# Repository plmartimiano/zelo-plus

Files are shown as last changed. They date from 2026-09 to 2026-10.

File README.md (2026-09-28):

# Zelo+ — Dispenser Inteligente de Medicamentos (firmware ESP32)

Protótipo de hardware/firmware do dispenser automático de medicamentos para idosos (pacientes)
do projeto acadêmico Zelo+. Projeto PlatformIO (framework Arduino, placa `esp32dev`).

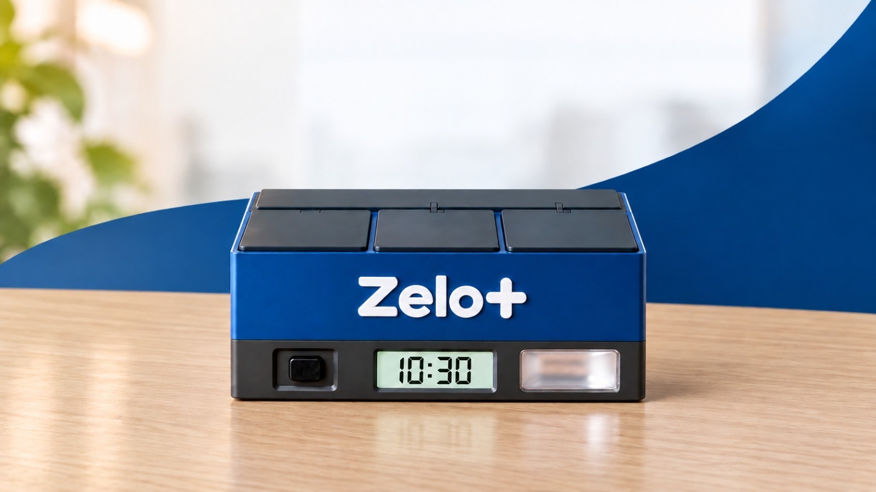
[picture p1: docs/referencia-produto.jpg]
Imagem de referência do produto Zelo+


*Imagem de referência — conceito visual do produto final (ilustrativo); não é o protótipo atual.*

Versão atual: **3 compartimentos** — até 3 medicamentos diferentes para o mesmo
paciente, cada um fixo no seu compartimento (detalhes em
[`docs/compartimentos.md`](docs/compartimentos.md)).

> 🛒 **Lista completa de componentes, com ilustrações e preços estimados:** Parte F do
> guia do produto.
> 📏 **Gabinete — 210 × 130 × 100 mm:** desenho técnico e imagens do produto na Parte B do
> guia do produto; vistas em escala em [`docs/gabinete.png`](docs/gabinete.png)
> ([SVG](docs/gabinete.svg)).
> 🏭 **Custo de produção em série (estimativa de viabilidade, set/2026):** Parte G do
> guia do produto — impressão 3D × plástico injetado, componentes no atacado e custo por
> unidade em 100, 1.000 e 10.000 unidades.
> 📘 **Guia do produto:** [`GUIA-DO-PRODUTO.md`](GUIA-DO-PRODUTO.md) explica o
> funcionamento passo a passo, com o trecho de código de cada etapa.
> Versão para impressão: [`docs/Zelo-Guia-do-Produto.pdf`](docs/Zelo-Guia-do-Produto.pdf).
> 🔌 **Ligações (bancada/testes):** [`docs/ligacoes.png`](docs/ligacoes.png) ([SVG](docs/ligacoes.svg)).
> 🔋 **Uso autônomo, após testes e atualização** — fonte 5 V/3 A + módulo **UPS LX-2BUPS** +
> baterias **18650** (lista de compras, montagem e teste) e relógio **DS3231**
> (opcional): Parte E do guia do produto e
> [`docs/ligacoes-autonomo.png`](docs/ligacoes-autonomo.png) ([SVG](docs/ligacoes-autonomo.svg)).

```
zelo-plus/
├── platformio.ini          # ambiente esp32dev + dependências
├── GUIA-DO-PRODUTO.md      # guia do produto
├── docs/compartimentos.md  # especificação aprovada dos 3 compartimentos
├── docs/ligacoes.png/.svg  # diagrama de todas as ligações (bancada)
├── docs/ligacoes-autonomo.*# montagem autônoma: fonte + módulo UPS + 18650 + DS3231
└── src/main.cpp            # firmware completo (máquina de estados + web + captive portal)
```

## Como compilar e gravar

1. Abra a pasta `zelo-plus/` no VSCode com a extensão PlatformIO.
2. Ajuste `upload_port` no `platformio.ini` (no Windows: Gerenciador de Dispositivos →
   "Silicon Labs CP210x USB to UART Bridge"), ou remova a linha para autodetecção.
3. `PlatformIO: Upload` e depois `PlatformIO: Monitor` (115200 baud).

## Fluxo de funcionamento

1. Cuidador acessa a página web servida pelo ESP32 e cadastra o paciente, até **3
   medicamentos** (um por compartimento, até 6 horários cada), cuidador, até 5
   familiares (opcionais) e o bot do Telegram.
2. A página indica onde colocar cada remédio ("Coloque LOSARTANA no compartimento 1").
   Cada compartimento que recebe um medicamento **novo** abre para abastecimento, **um
   de cada vez**; só mudar horários não abre nada.
3. O compartimento fecha pelo botão físico (trava de 7 s contra toque duplo) ou
   sozinho após 3 minutos.
4. No horário: buzzer + LED piscando e, no LCD, nome e compartimento do remédio
   (alternando se houver mais de um).
5. Paciente aperta o botão **uma vez** → alarme para e **todos os compartimentos daquela
   dose abrem**, um servo logo após o outro (nunca dois ao mesmo tempo).
   Se não aparecer, o alarme segue o ciclo de avisos (ver abaixo).
6. Paciente retira os remédios e fecha pelo botão (um toque fecha todos, após a trava
   de 7 s) ou timeout de 3 min.
7. Repete todo dia nos mesmos horários. Um horário que chega com algum compartimento
   aberto espera ele fechar e toca em seguida.
8. **Reposição:** a página pergunta qual medicamento será reposto, confirma e abre
   **só o compartimento dele**.
9. **Esvaziar compartimento:** apaga o cadastro daquele medicamento e, se o cuidador
   quiser, abre o compartimento para retirar as sobras.

## Hardware e pinagem

| Função | GPIO |
|---|---|
| Buzzer (ativo) | 15 |
| LED (+ resistor 220–330 Ω) | 4 |
| Botão (INPUT_PULLUP, outra perna no GND) | 5 |
| Servo compartimento 1 (sinal) | 13 |
| Servo compartimento 2 (sinal) | 14 |
| Servo compartimento 3 (sinal) | 27 |
| LCD I2C 16x2 (PCF8574, `0x27`) — SDA | 21 |
| LCD I2C — SCL | 22 |

- Servos: 0° = fechado, 90° = aberto (ajustáveis por compartimento em
  `ANGULO_FECHADO` / `ANGULO_ABERTO`). **Alimentação externa de 5 V (≥ 2 A)**, com GND
  compartilhado com o ESP32; o firmware nunca move dois servos ao mesmo tempo.
- O GPIO 12 foi evitado: ele interfere na inicialização do ESP32.
- Etiquetas **1, 2 e 3** na caixa, na mesma ordem da página.
- LCD: GND→GND, VCC→3V3, SDA→21, SCL→22.

## Relógio DS3231 (opcional)

Módulo RTC no mesmo I2C do LCD, em paralelo (`0x68`): VCC→3V3, GND→GND, SDA→21,
SCL→22, bateria **LIR2032**. Biblioteca `adafruit/RTClib`.

- **Sem o módulo:** `rtc.begin()` falha ao ligar e tudo segue pela hora da internet
  (NTP), como antes. O módulo pode ser instalado depois, sem regravar o firmware
  (com o dispenser desligado).
- **Ao ligar:** se o módulo tem hora válida (`!lostPower()` e data ≥ 2024), acerta o
  relógio do ESP32 com `settimeofday()` antes do Wi-Fi.
- **Com internet:** a cada sincronização do NTP (callback do SNTP) a hora é gravada no
  módulo pelo `loop()`, sem disputar o I2C com o LCD. O módulo guarda UTC.
- **Sem internet ao ligar:** com rede salva e hora do módulo, entra no modo normal
  (LCD `Sem internet` / `Hora do relogio`), os alarmes funcionam e o Wi-Fi é tentado a
  cada 30 s. Sem o módulo, o comportamento continua o de antes (portal de configuração).
- O rodapé da página mostra "Relógio DS3231: conectado" ou "não instalado".

## Wi-Fi (captive portal)

Não há credenciais fixas no código. Sem rede salva (ou se a conexão falhar), o ESP32
cria a rede aberta **ZeloPlus-Config**; ao conectar, o celular abre a página em
`192.168.4.1`, onde o cuidador escolhe a rede e digita a senha. A rede fica salva em
`Preferences` (namespace `wifi`). O link "Trocar rede Wi-Fi" apaga a rede e reinicia no
modo de configuração.

## Persistência do cadastro

Tudo fica em `Preferences` (namespace `cadastro`) e é recarregado no `setup()`:

- `nome` — paciente;
- `m0_*`, `m1_*`, `m2_*` — medicamento de cada compartimento (`_nome`, `_tot`,
  `_hr`, `_mn`), ou seja, a ligação medicamento ↔ compartimento;
- `cuid_*` / `fam0_*` … `fam4_*` — contatos; `tg_token` — bot do Telegram.

O cadastro da versão de um compartimento (`remedio`, `total`, `horas`, `minutos`)
migra sozinho para o compartimento 1 na primeira vez que esta versão liga.

## Ciclo do alarme e avisos pelo Telegram

| Tempo desde o horário | O que acontece |
|---|---|
| 0–1 min, 2–3, 4–5, 6–7, 8–9, 10–11 | Buzzer + LED tocando |
| 1–2 min, 3–4, 5–6, 7–8, 9–10, 11–12 | Silêncio (o botão continua funcionando) |
| 6 min sem acesso | Telegram para o **cuidador**: Zelo+: Paciente “Nome” não acessou o medicamento das “HH:MM” horas (Losartana). |
| 12 min sem acesso | Alarme para; Telegram para **cuidador e familiares**: Zelo+: Paciente “Nome” não foi até o dispenser no horário das “HH:MM” (Losartana e Metformina). |
| Depois dos 12 min | LCD mostra "Dose pendente!"; o botão ainda abre os compartimentos da dose |
| Paciente acessa após um aviso | Quem foi avisado recebe "paciente acessou o dispenser às HH:MM" |

### Por que Telegram

Comparação das opções para o ESP32 enviar avisos:

- **Bot do Telegram (escolhido)** — gratuito, API oficial, sem limite de vagas,
  uma requisição HTTPS direto do ESP32. Cada pessoa só precisa abrir o bot e tocar
  em "Iniciar".
- **CallMeBot (WhatsApp)** — foi a primeira escolha, mas o serviço ficou lotado
  (sem vagas para novos números) e o plano gratuito é só para uso pessoal.
- **Twilio WhatsApp** — oficial e confiável, mas pago, exige número aprovado e
  modelos de mensagem aprovados pela Meta.
- **WhatsApp Cloud API (Meta)** — oficial, exige conta Business verificada,
  modelos aprovados e token que expira; complexo para rodar só no ESP32.

Para um produto real com WhatsApp, o caminho recomendado é o ESP32 avisar um
backend, e o backend enviar pela API oficial (Twilio ou Meta).

### Como configurar

1. **Uma vez só (cuidador):** no Telegram, abrir o **@BotFather**, enviar `/newbot`,
   escolher um nome e um usuário terminado em `bot` (ex.: `zelo_maria_bot`).
   Copiar o **token** e colar no campo "Token do bot" da página de cadastro.
2. **Cada pessoa** (cuidador e familiares) procura o bot no Telegram e toca em
   **Iniciar**.
3. Na página, tocar em **Buscar IDs do Telegram**: aparecem o nome e o ID de quem
   iniciou o bot nas últimas 24 horas. Copiar cada ID para o campo da pessoa e salvar.
4. Usar **Enviar mensagem de teste no Telegram** para conferir.

O token fica salvo na placa (Preferences, chave `tg_token`) e não é mostrado de
volta na página; deixar o campo em branco ao salvar mantém o token atual. A conexão
HTTPS não valida o certificado (`setInsecure`), o que é aceitável no protótipo, mas
deve ser revisto num produto.

## Histórico de doses

Cada vez que um alarme dispara, o Zelo+ cria **um registro por medicamento** com data,
horário, medicamento, compartimento e situação, guardado na placa (`Preferences`,
namespace `historico`, últimas 60 doses):

| Situação | Quando |
|---|---|
| Tomada no horário | Paciente apertou o botão antes do primeiro aviso (6 min; 30 s no modo teste) |
| Tomada com atraso | Apertou depois do primeiro aviso, inclusive depois do alerta final (o tempo de atraso é registrado) |
| Sem acesso | Alerta final enviado e ninguém apertou o botão |
| Tocando agora | Alarme em andamento |

Na página aparecem o **resumo dos últimos 7 dias** (percentual de adesão geral e por
medicamento, e contagem por situação), as **20 doses mais recentes** e o link **Baixar histórico completo
(planilha CSV)**, que abre no Excel/Google Planilhas (separador `;`, colunas
data, horário, medicamento, compartimento, situação e atraso). O botão
"Apagar histórico" limpa todos os registros.

Adesão = (doses tomadas no horário + com atraso) ÷ doses concluídas no período.

## Máquina de estados (`loop()`)

Os horários são conferidos a cada segundo em qualquer estado; se o dispenser estiver
ocupado, ficam em espera (`mascaraEmEspera`) e tocam quando ele voltar a `AGUARDANDO`.

- `AGUARDANDO` — relógio no LCD; inicia alarmes em espera e, depois, o abastecimento
  de compartimentos novos (`filaAbastecimento`, um de cada vez).
- `TOCANDO` — ciclo 1 min tocando / 1 min silêncio por até 12 min, com avisos aos 6 e 12 min.
- `PORTA_ABERTA_ESTADO` — compartimentos da dose abertos; botão (após 7 s) ou timeout
  de 3 min fecha todos.
- `ABASTECENDO` — um compartimento aberto para o cuidador (abastecer, repor ou esvaziar).

`modoConfig` separa o modo de configuração de Wi-Fi do modo normal.

## Limitações conhecidas

1. Um paciente e até 3 medicamentos (`NUM_COMPARTIMENTOS`).
2. Máximo de 6 horários por medicamento (`MAX_HORARIOS`).
3. O captive portal pode não abrir sozinho em alguns celulares (abrir o navegador
   manualmente funciona).
4. Sem HTTPS/autenticação: qualquer pessoa na mesma rede pode alterar o cadastro.
5. Envio de mensagens trava o dispenser por alguns segundos (até ~10 s por
   contato se a internet estiver lenta).
6. Se a placa reiniciar dentro do minuto de um alarme que já tocou, ele pode tocar de
   novo (o controle "já disparado" fica só em RAM).

## Decisões de projeto

- Página web no próprio ESP32, para o cuidador não mexer no firmware.
- Trava de 7 s no botão contra fechamento acidental por toque duplo.
- Abertura automática só quando um compartimento recebe medicamento novo.
- Cada medicamento fica fixo no seu compartimento; reposição escolhe o medicamento
  e abre só o compartimento dele, com confirmação.
- Dose com mais de um remédio: um único toque abre todos, servos em sequência.
- Wi-Fi configurável por portal, para replicar o dispositivo em outros locais.

## Próximos passos sugeridos

- Autenticação simples na página web.
- Integração com backend/app do cuidador para monitoramento remoto.
- Testar o captive portal em mais modelos de celular.
- Validar fiação/protoboard para uso contínuo (certificação, testes com ILPIs).

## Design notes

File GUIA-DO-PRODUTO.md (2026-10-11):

# Zelo+ — Guia do produto

> Este guia apresenta o dispenser inteligente de medicamentos Zelo+: a concepção do
> produto, o desenho técnico do gabinete, o funcionamento do programa (com o **trecho de
> código** de cada etapa; o arquivo completo está em [`src/main.cpp`](src/main.cpp)), a
> montagem para uso autônomo, a lista de componentes, a estimativa de custo de produção
> e as propostas de evolução com inteligência artificial.

<!-- so-github -->
Imagem de referência do produto Zelo+

*Imagem de referência — conceito visual do produto final (ilustrativo).*
<!-- /so-github -->

---

## Sumário

- [Missão, visão e valores](#missão-visão-e-valores)
- [Sumário executivo](#sumário-executivo)
- [Parte A — Entendendo o projeto](#parte-a--entendendo-o-projeto)
  - [A1. O que é o Zelo+](#a1-o-que-é-o-zelo)
  - [A2. Materiais e ligações](#a2-materiais-e-ligações)
  - [A3. Ambiente de desenvolvimento](#a3-ambiente-de-desenvolvimento)
  - [A4. Cinco conceitos antes de começar](#a4-cinco-conceitos-antes-de-começar)
  - [A5. A página do Zelo+ (tela completa)](#a5-a-página-do-zelo-tela-completa)
- [Parte B — Desenho técnico do gabinete](#parte-b--desenho-técnico-do-gabinete)
  - [B1. Desenho técnico dimensional](#b1-desenho-técnico-dimensional)
  - [B2. Imagens do produto](#b2-imagens-do-produto)
  - [B3. Critérios de projeto](#b3-critérios-de-projeto)
  - [B4. Onde fica cada componente](#b4-onde-fica-cada-componente)
  - [B5. Abertura de emergência sem energia](#b5-abertura-de-emergência-sem-energia)
  - [B6. Modelo 3D do gabinete e impressão](#b6-modelo-3d-do-gabinete-e-impressão)
- [Parte C — O código, passo a passo](#parte-c--o-código-passo-a-passo)
  - [Passo 1 — Bibliotecas e pinos](#passo-1--bibliotecas-e-pinos)
  - [Passo 2 — Estruturas de dados](#passo-2--estruturas-de-dados)
  - [Passo 3 — `setup()`: ligando tudo](#passo-3--setup-ligando-tudo)
  - [Passo 4 — Wi-Fi sem senha no código (captive portal)](#passo-4--wi-fi-sem-senha-no-código-captive-portal)
  - [Passo 5 — Modo normal: relógio pela internet e rotas da página](#passo-5--modo-normal-relógio-pela-internet-e-rotas-da-página)
  - [Passo 6 — Memória permanente (Preferences)](#passo-6--memória-permanente-preferences)
  - [Passo 7 — A página de cadastro](#passo-7--a-página-de-cadastro)
  - [Passo 8 — Salvando o cadastro](#passo-8--salvando-o-cadastro)
  - [Passo 9 — Movendo as portas (servos)](#passo-9--movendo-as-portas-servos)
  - [Passo 10 — O coração: `loop()` e a máquina de estados](#passo-10--o-coração-loop-e-a-máquina-de-estados)
  - [Passo 11 — Conferindo os horários](#passo-11--conferindo-os-horários)
  - [Passo 12 — O alarme tocando](#passo-12--o-alarme-tocando)
  - [Passo 13 — O paciente aperta o botão](#passo-13--o-paciente-aperta-o-botão)
  - [Passo 14 — Abastecer, repor e esvaziar](#passo-14--abastecer-repor-e-esvaziar)
  - [Passo 15 — Avisos pelo Telegram](#passo-15--avisos-pelo-telegram)
  - [Passo 16 — Histórico de doses](#passo-16--histórico-de-doses)
  - [Passo 17 — Escrevendo no LCD](#passo-17--escrevendo-no-lcd)
  - [Passo 18 — Modo de teste](#passo-18--modo-de-teste)
  - [Passo 19 — Relógio DS3231 (próxima etapa)](#passo-19--relógio-ds3231-próxima-etapa)
  - [Passo 20 — Leitura da caixa do remédio por foto (IA)](#passo-20--leitura-da-caixa-do-remédio-por-foto-ia)
  - [Passo 21 — Modo do cuidador: abrir pelo botão, sem o celular](#passo-21--modo-do-cuidador-abrir-pelo-botão-sem-o-celular)
- [Parte D — Juntando tudo](#parte-d--juntando-tudo)
  - [D1. Linha do tempo de uma dose](#d1-linha-do-tempo-de-uma-dose)
  - [D2. Referência rápida](#d2-referência-rápida)
- [Parte E — Uso autônomo, sem o laptop](#parte-e--uso-autônomo-sem-o-laptop)
  - [E1. Pré-requisitos e validação](#e1-pré-requisitos-e-validação)
  - [E2. Por que o laptop não é necessário](#e2-por-que-o-laptop-não-é-necessário)
  - [E3. A solução: fonte 5 V/3 A + módulo UPS + bateria 18650](#e3-a-solução-fonte-5-v3-a--módulo-ups--bateria-18650)
  - [E4. Lista de compras](#e4-lista-de-compras)
  - [E5. Montagem passo a passo](#e5-montagem-passo-a-passo)
  - [E6. Teste de falta de energia](#e6-teste-de-falta-de-energia)
  - [E7. Autonomia da bateria](#e7-autonomia-da-bateria)
  - [E8. Falta de energia e de internet](#e8-falta-de-energia-e-de-internet)
  - [E9. Módulo de relógio DS3231](#e9-módulo-de-relógio-ds3231)
  - [E10. Atualizar o programa depois de montado](#e10-atualizar-o-programa-depois-de-montado)
  - [E11. Procedimento de emergência](#e11-procedimento-de-emergência)
- [Parte F — Lista completa de componentes, com preços](#parte-f--lista-completa-de-componentes-com-preços)
  - [F1. Eletrônica do dispenser](#f1-eletrônica-do-dispenser)
  - [F2. Energia autônoma](#f2-energia-autônoma)
  - [F3. Montagem e ligações](#f3-montagem-e-ligações)
  - [F4. Relógio sem internet (próxima etapa)](#f4-relógio-sem-internet-próxima-etapa)
  - [F5. Ferramentas necessárias (fora do custo)](#f5-ferramentas-necessárias-fora-do-custo)
  - [F6. Resumo do investimento](#f6-resumo-do-investimento)
- [Parte G — Custo de produção (estimativa para viabilidade)](#parte-g--custo-de-produção-estimativa-para-viabilidade)
  - [G1. Premissas e método](#g1-premissas-e-método)
  - [G2. Volume de plástico do gabinete](#g2-volume-de-plástico-do-gabinete)
  - [G3. Gabinete em impressão 3D](#g3-gabinete-em-impressão-3d)
  - [G4. Gabinete em plástico injetado](#g4-gabinete-em-plástico-injetado)
  - [G5. Componentes eletrônicos no atacado](#g5-componentes-eletrônicos-no-atacado)
  - [G6. Custo por unidade em três escalas](#g6-custo-por-unidade-em-três-escalas)
  - [G7. Investimentos iniciais (uma vez só)](#g7-investimentos-iniciais-uma-vez-só)
  - [G8. Preço de venda e viabilidade](#g8-preço-de-venda-e-viabilidade)
  - [G9. Limitações da estimativa](#g9-limitações-da-estimativa)
- [Parte H — Evolução do produto: funcionalidades com inteligência artificial](#parte-h--evolução-do-produto-funcionalidades-com-inteligência-artificial)
  - [H1. Princípios de projeto](#h1-princípios-de-projeto)
  - [H2. Arquitetura proposta](#h2-arquitetura-proposta)
  - [H3. Funcionalidades propostas](#h3-funcionalidades-propostas)
  - [H4. Quadro-resumo dos impactos](#h4-quadro-resumo-dos-impactos)
  - [H5. Impactos gerais da mudança](#h5-impactos-gerais-da-mudança)
  - [H6. Etapas de implantação](#h6-etapas-de-implantação)
  - [H7. Modelo próprio de IA (etapa futura)](#h7-modelo-próprio-de-ia-etapa-futura)
- [Referências](#referências)

---

# Missão, visão e valores

<figure markdown="1">
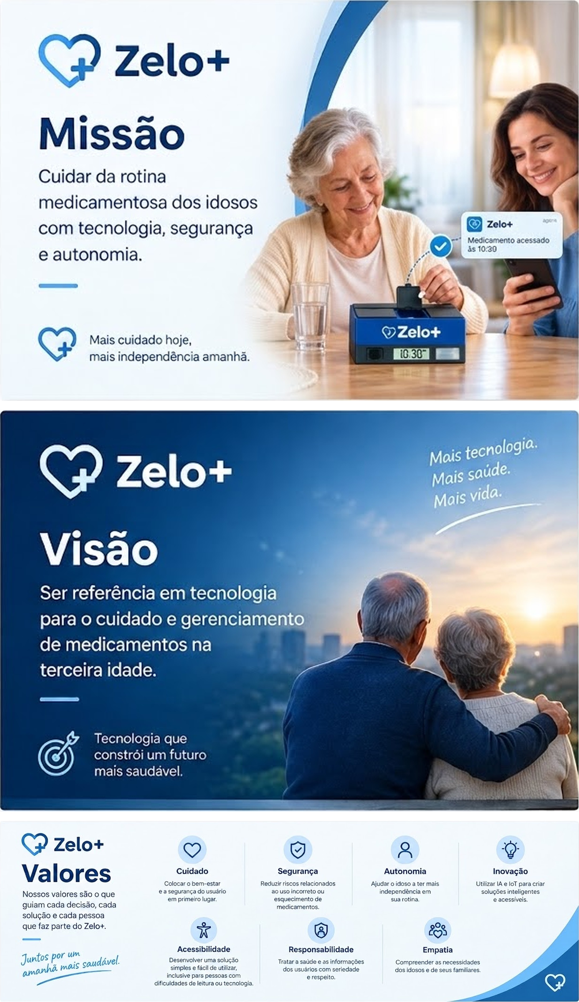
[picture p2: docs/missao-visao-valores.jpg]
Missão, visão e valores do Zelo+

<figcaption><b>Missão, visão e valores do Zelo+.</b></figcaption>
</figure>

---

# Sumário executivo

> O Zelo+ é um dispenser automático de medicamentos para idosos, com aviso ao cuidador
> pelo celular. Este sumário apresenta o problema tratado, o valor pretendido, a forma de
> entrega em ciclos curtos, os indicadores de sucesso, os riscos e os próximos marcos.
> O escopo detalhado é refinado a cada ciclo, com base no retorno de pacientes e
> cuidadores.

## Problema e necessidade

| Quem sofre | Dor |
|---|---|
| **Paciente idoso** | Uso de vários medicamentos em horários diferentes, com risco de esquecer doses, tomar em dobro ou confundir os remédios. |
| **Cuidador e família** | Falta de informação confiável sobre o que foi tomado e quando; o acompanhamento depende da memória do paciente ou de visitas. |
| **Profissional de saúde** | Ausência de dados objetivos de adesão ao tratamento na hora da consulta. |

**Oportunidade:** um dispositivo de mesa, simples para o paciente, que organiza as doses,
avisa no horário e mantém a família informada, a um custo compatível com o uso doméstico.

## Visão do produto e objetivos de valor

**Visão:** ser referência em tecnologia para o cuidado e o gerenciamento de medicamentos
na terceira idade.

| Objetivo de valor | Como o Zelo+ entrega hoje |
|---|---|
| **Dose certa, na hora certa** | Três compartimentos com porta motorizada; no horário, alarme sonoro, luz e mensagem colorida na tela; um botão abre somente o compartimento da dose. |
| **Família informada** | Aviso pelo Telegram quando a dose não é retirada (primeiro aviso aos 6 min e alerta final aos 12 min). |
| **Configuração sem técnico** | Página no celular para cadastrar remédios, horários e familiares, com abastecimento guiado e leitura da caixa do remédio por foto. |
| **Funciona mesmo sem internet** | Rede própria do dispenser quando o Wi-Fi da casa falha, novas tentativas automáticas e bateria para faltas de energia. |
| **Informação para a consulta** | Histórico de doses e taxa de adesão por medicamento, com exportação em planilha. |

## Abordagem e incrementos

A entrega é feita em **ciclos quinzenais**, cada um com um incremento utilizável e
validado em bancada ou com usuários, em vez de fases longas e sequenciais.

| Incremento | Valor entregue | Situação |
|---|---|---|
| **1. Núcleo do dispenser** | Alarmes, portas, botão, tela, página no celular, avisos pelo Telegram, histórico e adesão | Concluído (protótipo funcional) |
| **2. Robustez** | Montagem autônoma (fonte e bateria), relógio DS3231 para manter a hora sem internet, tempos definitivos de uso | Próximo ciclo |
| **3. IA — 1ª etapa** | Cadastro por foto ou código de barras, conferência na reposição e relatório de adesão (H3.1, H3.2, H3.6) | Leitura por foto já integrada; demais itens planejados |
| **4. IA — 2ª etapa** | Cadastro pela receita e assistente do cuidador no Telegram (H3.4, H3.7) | Planejado |
| **5. Acessibilidade** | Voz para o paciente (H3.11) | Planejado, depende de componente |
| **6. Modelo próprio de IA** | Leitura de embalagens sem serviço de terceiros (H7) | Horizonte de cerca de 12 meses |

## Indicadores de sucesso

| Indicador | Como medir | Meta proposta |
|---|---|---|
| **Adesão ao tratamento** | Doses tomadas ÷ doses previstas (histórico do próprio dispenser) | ≥ 90 % nos usuários do lote piloto |
| **Doses no horário** | Doses retiradas antes do primeiro aviso ÷ doses tomadas | Crescente a cada ciclo |
| **Tempo de reação da família** | Intervalo entre o alerta no Telegram e a retirada da dose | Redução a cada ciclo |
| **Facilidade de uso** | Tempo para cadastrar um remédio e taxa de tarefas concluídas sem ajuda | Cadastro em até 3 min |
| **Satisfação** | NPS de cuidadores e pacientes ao fim de cada ciclo de teste | NPS ≥ 50 |
| **Confiabilidade** | Falhas de porta, reinícios e horas sem hora certa por mês | Zero falha que impeça a dose |
| **Viabilidade** | Custo de fabricação por unidade (Parte G) | R$ 161–254 em série |

## Principais riscos e premissas

| Risco ou premissa | Estratégia de adaptação |
|---|---|
| **Enquadramento como dispositivo médico (Anvisa)** | Consulta regulatória antes da venda; funções de IA apenas informativas, sem bloquear ou alterar a prescrição. |
| **Proteção de dados de saúde (LGPD)** | Consentimento, envio mínimo de dados, chaves somente no serviço e opção de exclusão. |
| **Dependência de internet e de serviços de terceiros** | A rotina de doses funciona sem conexão; a IA é complementar e terá alternativa própria (H7). |
| **Falta de energia ou de hora certa** | Bateria com módulo UPS e relógio DS3231; aviso "Acerte a hora" e ajuste pelo celular; power bank na entrada USB-C e liberação manual das portas, sem energia (E11). |
| **Durabilidade mecânica** | Ensaios de ciclo de abertura; troca do SG90 pelo MG90S (engrenagem de metal) se necessário. |
| **Custo e câmbio** | Faixas de custo revisadas a cada ciclo; produção em lote piloto por impressão 3D antes de investir em moldes. |
| **Premissa de uso** | Paciente com autonomia para apertar um botão e cuidador com celular e Telegram; validada no lote piloto. |

## Próximos passos

| Marco | Entregas |
|---|---|
| **Próximo ciclo** | Montagem autônoma com fonte e bateria, relógio DS3231, tempos definitivos e ensaio completo da validação de pré-requisitos (E1). |
| **Release de validação** | Lote piloto de cerca de 100 unidades em impressão 3D, testes com famílias e coleta dos indicadores acima. |
| **Ciclos seguintes** | Etapas de IA conforme o retorno dos usuários, consulta regulatória e homologação na Anatel antes da comercialização. |

**Investimento de referência:** cerca de R$ 303–403 para montar um protótipo (Parte F);
custo de R$ 162–257 por unidade em série, com preço de venda estimado de R$ 400 a
R$ 1.030 (Parte G).

---

# Parte A — Entendendo o projeto

## A1. O que é o Zelo+

O Zelo+ é um **dispenser automático de medicamentos** para pacientes (em especial
idosos). Ele tem **3 compartimentos**, cada um com um remédio diferente e com uma
porta movida por um servo motor.

<figure markdown="1">
Imagem de referência do produto Zelo+
<figcaption><b>Imagem de referência</b> — conceito visual do produto final (ilustrativo), com o botão à esquerda, a tela no centro e a luz de alerta à direita.</figcaption>
</figure>

<figure markdown="1">
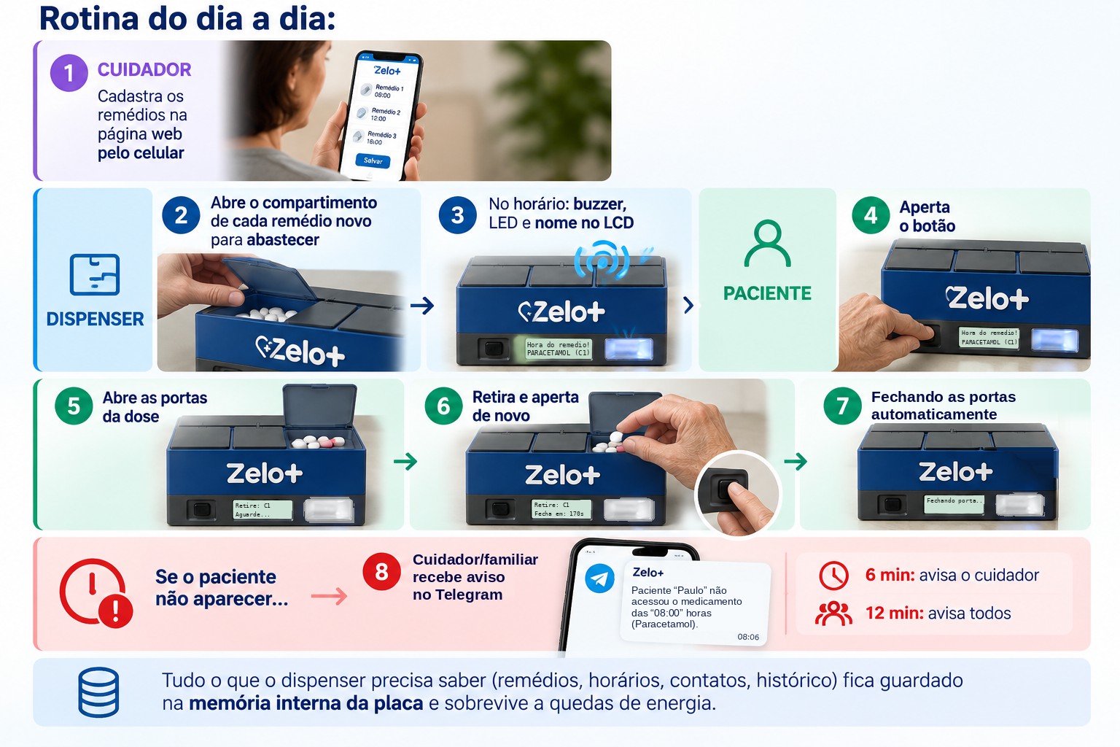
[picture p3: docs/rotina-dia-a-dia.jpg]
Rotina do dia a dia com o Zelo+

<figcaption><b>Rotina do dia a dia</b> — cuidador, dispenser e paciente, do cadastro dos remédios aos avisos pelo Telegram.</figcaption>
</figure>

## A2. Materiais e ligações

| Componente | Quantidade | Observação |
|---|---|---|
| ESP32 DevKit (30 pinos) | 1 | O "cérebro". Tem Wi-Fi embutido. |
| Servo motor SG90 | 3 | Um por compartimento (porta). |
| Tela TFT 2,25" colorida (ST7789P3, 76 × 284 pontos, ligação SPI) | 1 | Mostra relógio, nome do remédio e avisos, com cores por situação. |
| Buzzer **ativo** | 1 | Apita sozinho quando recebe energia. |
| LED + resistor 220–330 Ω | 1 | Pisca junto com o buzzer. |
| Botão (push-button) | 1 | O paciente aperta para abrir/fechar. |
| Fonte externa 5 V (≥ 2 A) | 1 | Alimenta os servos. |
| Relógio DS3231 + bateria LIR2032 *(próxima etapa)* | 1 | Guarda a hora sem internet ([Passo 19](#passo-19--relógio-ds3231-próxima-etapa)). |
| Protoboard e jumpers | — | Ligações. |

<figure markdown="1">
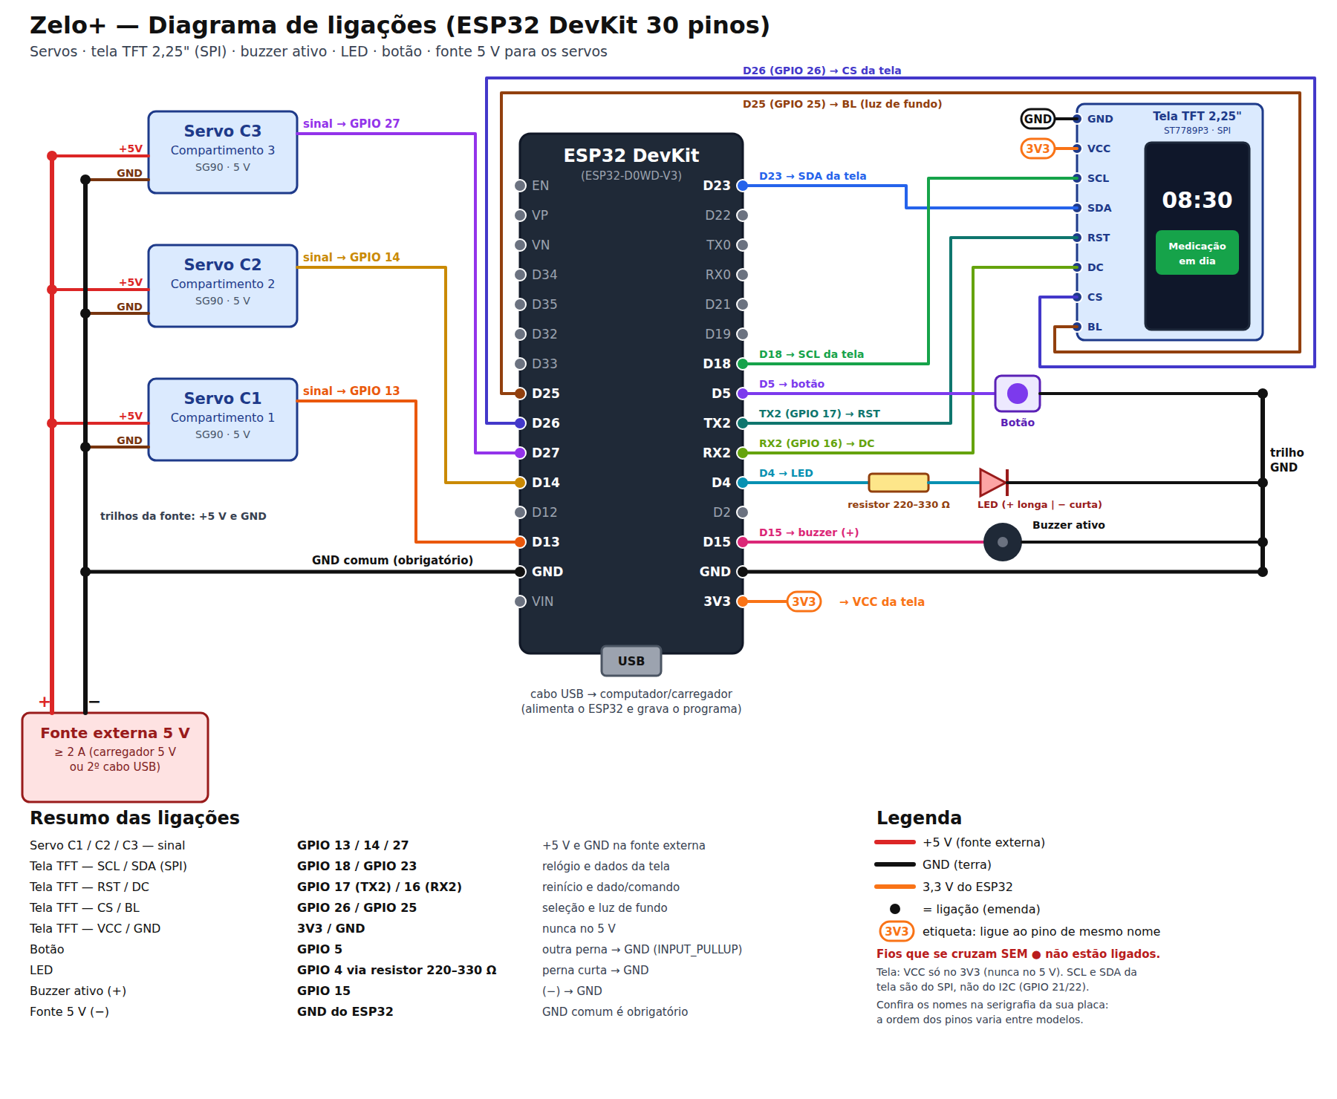
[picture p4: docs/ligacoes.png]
Diagrama de ligações do Zelo+

<figcaption><b>Diagrama de ligações da montagem de bancada.</b> Versão vetorial, que pode ser ampliada sem perda de qualidade: <code>docs/ligacoes.svg</code>.</figcaption>
</figure>

| Ligação | Pino do ESP32 | Detalhe |
|---|---|---|
| Servo compartimento 1 (sinal) | GPIO 13 | +5 V e GND na **fonte externa** |
| Servo compartimento 2 (sinal) | GPIO 14 | +5 V e GND na **fonte externa** |
| Servo compartimento 3 (sinal) | GPIO 27 | +5 V e GND na **fonte externa** |
| Tela TFT — SCL / SDA | GPIO 18 / GPIO 23 | relógio e dados do SPI |
| Tela TFT — RST / DC | GPIO 17 (TX2) / GPIO 16 (RX2) | reinício da tela / dado ou comando |
| Tela TFT — CS / BL | GPIO 26 / GPIO 25 | seleção da tela / luz de fundo |
| Tela TFT — VCC / GND | 3V3 / GND | **nunca no 5 V** |
| Relógio DS3231 — SDA / SCL *(próxima etapa)* | GPIO 21 / GPIO 22 | único no I2C; VCC → 3V3, GND → GND (desenho na [E3](#e3-a-solução-fonte-5-v3-a--módulo-ups--bateria-18650)) |
| Botão | GPIO 5 | outra perna → GND (sem resistor) |
| LED | GPIO 4 | via resistor; perna curta → GND |
| Buzzer (+) | GPIO 15 | (−) → GND |
| Fonte externa (−) | GND do ESP32 | **GND comum obrigatório** |

**Por que uma fonte separada para os servos?** Um servo puxa muita corrente no
momento em que começa a girar. Se ele for ligado no 3V3 do ESP32, a tensão cai e a
placa reinicia. Por isso os servos usam uma fonte de 5 V própria, e o **GND da fonte
é ligado ao GND do ESP32**: sem essa referência comum, o sinal do pino não é
entendido pelo servo.

**Ligação da tela TFT.** O módulo tem 8 pinos: GND, VCC, SCL, SDA, RST, DC, CS e BL.
Apesar dos nomes, **SCL e SDA da tela são do SPI** (relógio e dados), não do I2C: vão
nos GPIO 18 e 23, e não nos GPIO 21 e 22. Na placa, os GPIO 17 e 16 aparecem impressos
como **TX2** e **RX2**. O VCC vai no **3V3**: a tela trabalha com 3,3 V e pode ser
danificada no 5 V. O pino BL acende a luz de fundo; o ESP32 controla o brilho por ele.
O GPIO 19 fica reservado ao SPI, mesmo sem fio, e não deve ser usado para outra peça.

**Por que o GPIO 12 não foi usado?** Ele é um pino de "configuração de
inicialização" do ESP32; se estiver com algo ligado na hora de ligar a placa, ela
pode não iniciar.

## A3. Ambiente de desenvolvimento

- **VSCode** com a extensão **PlatformIO**.
- Placa `esp32dev`, framework **Arduino** (a mesma linguagem do Arduino, em C++).

O arquivo `platformio.ini` diz ao PlatformIO qual placa usar e quais bibliotecas
baixar:

```ini
[env:esp32dev]
platform = espressif32
board = esp32dev
framework = arduino
upload_port = COM3
monitor_speed = 115200
board_build.partitions = huge_app.csv
lib_deps = 
    marcoschwartz/LiquidCrystal_I2C^1.1.4
    madhephaestus/ESP32Servo^3.0.5
    bblanchon/ArduinoJson^7.0.4
    adafruit/RTClib^2.1.4
```

- `upload_port`: porta USB onde a placa aparece no Windows (varia de PC para PC).
- `monitor_speed`: velocidade do **Serial Monitor**, onde a placa escreve mensagens.
- `huge_app.csv`: reserva mais espaço para o programa (a parte de internet segura,
  HTTPS, deixa o firmware grande).
- `lib_deps`: bibliotecas do LCD, dos servos, de leitura de JSON (usada no Telegram)
  e do relógio DS3231 (`RTClib`).

**Para gravar:** ✓ (Build) → → (Upload) → 🔌 (Serial Monitor), na barra azul do
rodapé do VSCode.

## A4. Cinco conceitos antes de começar

1. **`setup()` e `loop()`** — todo programa Arduino tem essas duas funções. O
   `setup()` roda **uma vez** quando a placa liga; o `loop()` roda **para sempre**,
   milhares de vezes por segundo.

2. **`millis()` em vez de `delay()`** — `delay(1000)` congela a placa por 1 segundo
   (ela não lê o botão nem atende a página). Por isso o Zelo+ quase sempre usa
   `millis()`, que devolve "há quantos milissegundos a placa está ligada", e compara
   tempos:
   ```cpp
   if (millis() - ultimaAtualizacao < 1000) return;
   ```
   (se ainda não passou 1 segundo desde a última atualização, sai e tenta de novo
   na próxima volta do `loop()`, sem travar nada).

3. **Máquina de estados** — o dispenser está sempre em **um** estado (aguardando,
   tocando, porta aberta, abastecendo). Em cada estado ele faz coisas diferentes e,
   quando algo acontece, **muda de estado**. Isso deixa o comportamento previsível.

4. **Máscara de bits** — para dizer "compartimentos 1 e 3", o código usa um número
   em que cada **bit** representa um compartimento:
   ```text
   compartimento:   3 2 1
   bits:            1 0 1   = 5  →  compartimentos 1 e 3
   ```
   Assim uma única variável (`uint8_t`) guarda qualquer combinação de compartimentos.

5. **Memória permanente (Preferences/NVS)** — a variável comum some quando a energia
   cai. A biblioteca `Preferences` grava dados na **memória flash** da placa, que não
   se apaga ao desligar (como um pen drive).

## A5. A página do Zelo+ (tela completa)

É a página que o cuidador abre no celular, digitando o IP que aparece no LCD (ex.:
`192.168.15.152`). As imagens abaixo foram geradas **pelo próprio firmware** (a função
`handleRoot()` do Passo 7) com um cadastro de exemplo completo.

| ① Falta configurar o Telegram | ② Tudo configurado | ③ Blocos abertos |
|:---:|:---:|:---:|
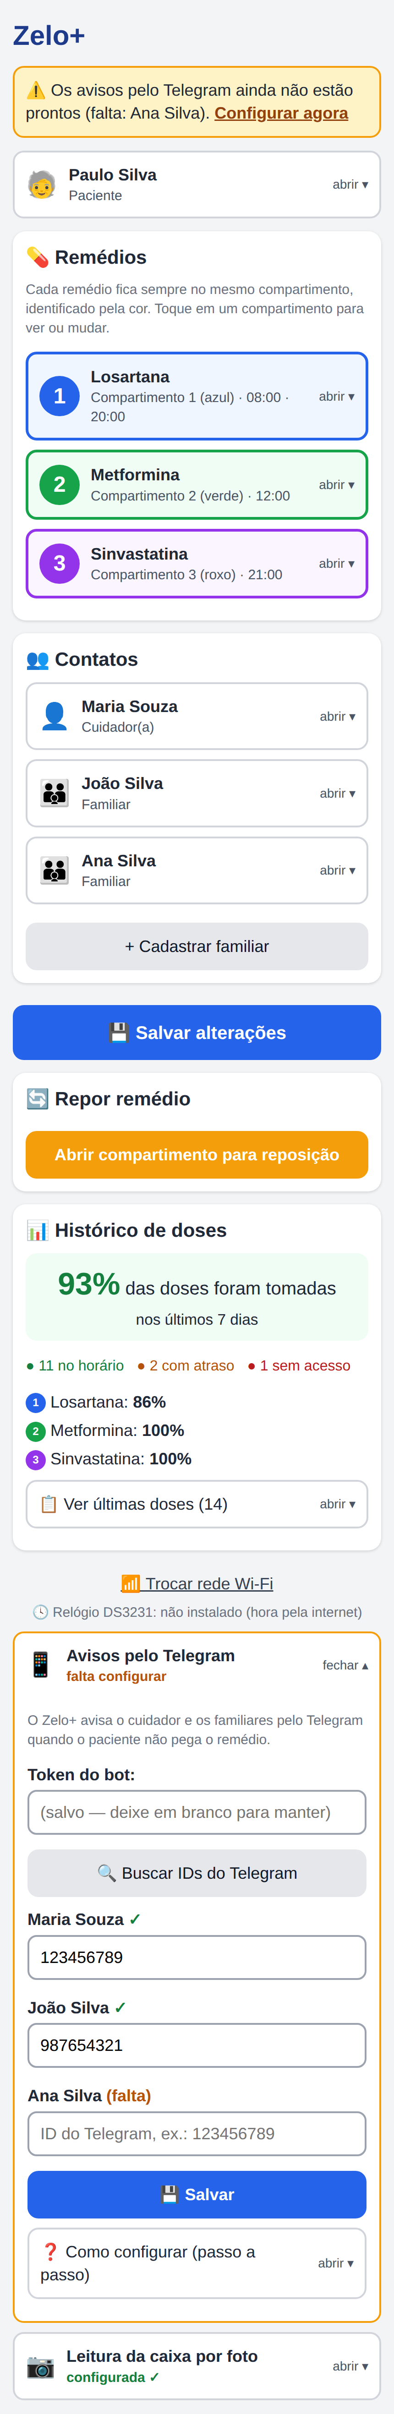
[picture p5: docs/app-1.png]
Página com aviso do Telegram
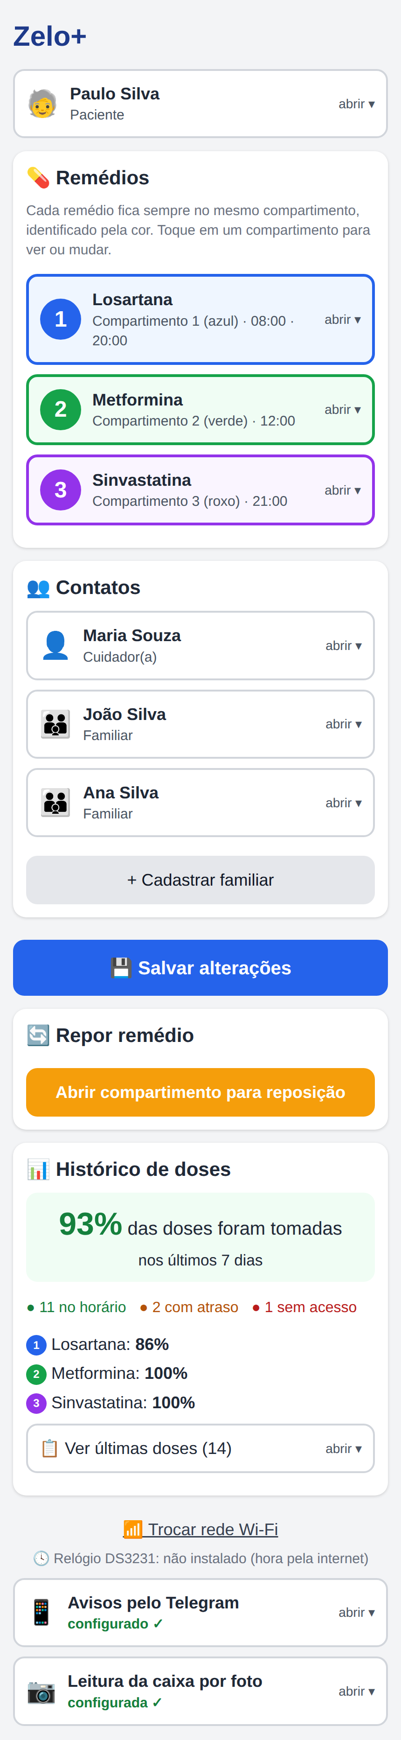
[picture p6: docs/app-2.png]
Página já configurada
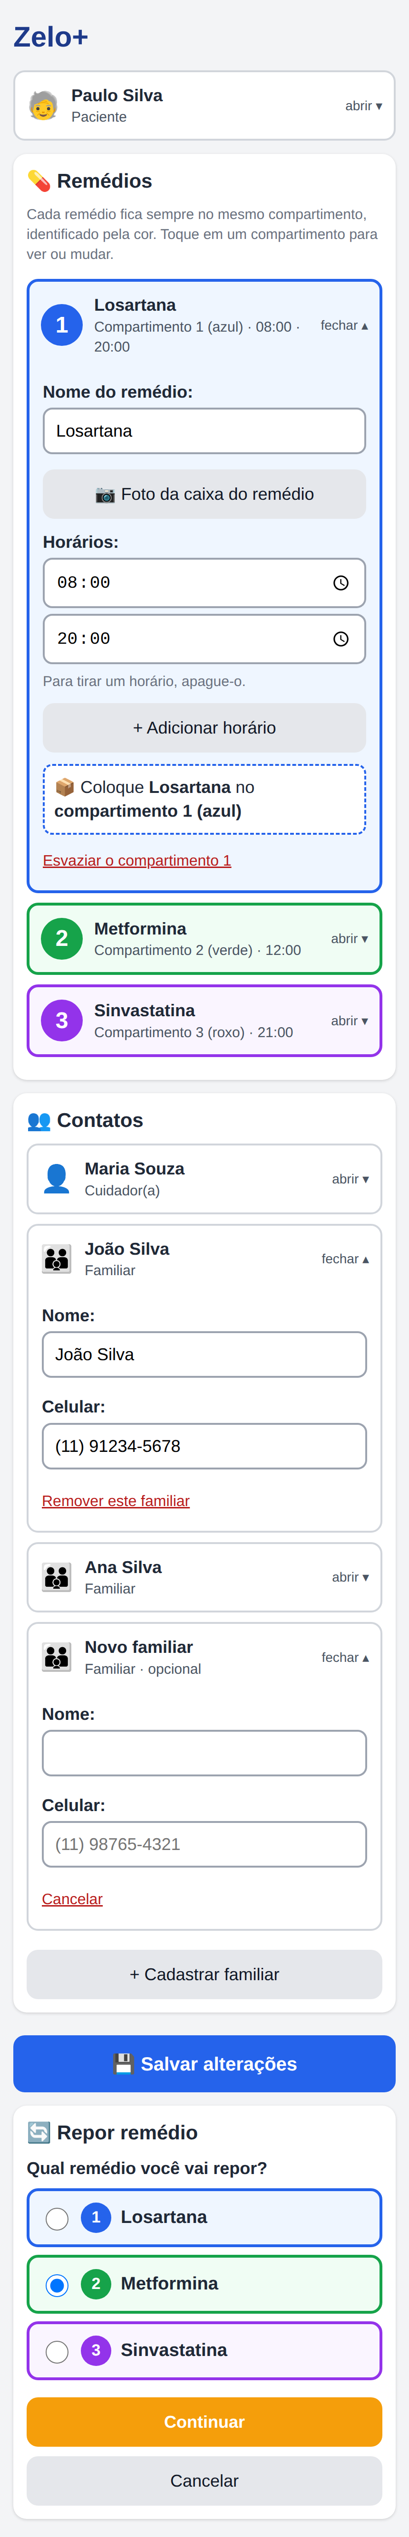
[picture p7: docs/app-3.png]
Página com blocos abertos
|  |  |  |

- **①** A familiar Ana ainda não tem ID do Telegram: aparece um **aviso amarelo no
  topo** e o bloco do Telegram (no fim da página) vem **aberto**, marcando quem falta.
- **②** Com tudo configurado, a página fica curta: o Telegram vira uma linha
  "configurado ✓" no rodapé.
- **③** O que aparece ao tocar: compartimento 1 em edição (nome, botão de foto da
  caixa, horários, dica
  "coloque no compartimento 1 (azul)"), o familiar João aberto, o formulário de um
  **familiar novo** e a **reposição**, com a escolha do remédio pelas cores.

<figure markdown="1">
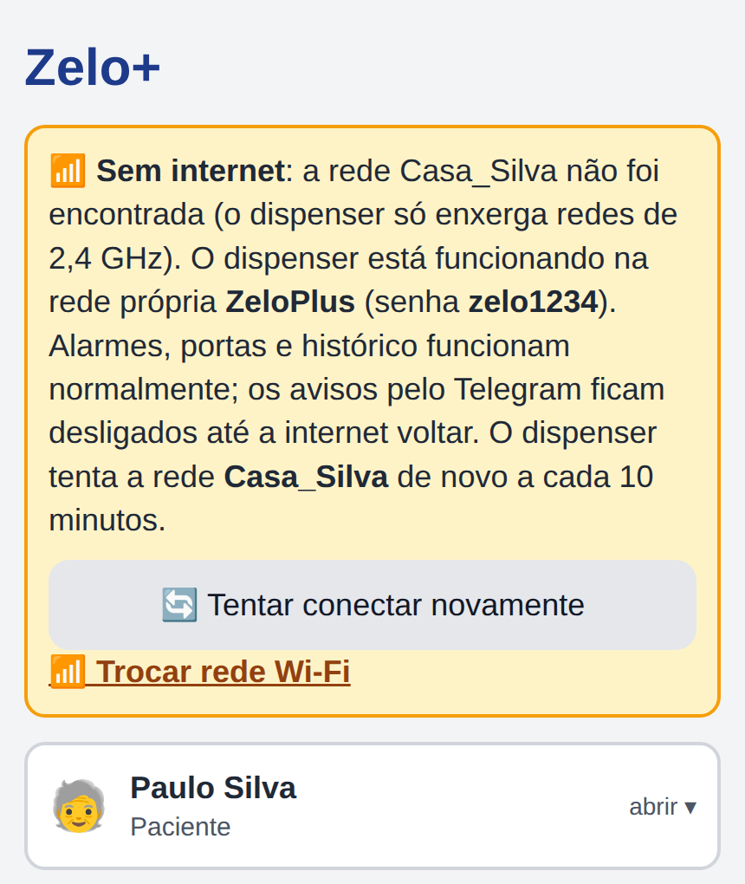
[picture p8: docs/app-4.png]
Página na rede própria, com o aviso de sem internet

<figcaption><b>④ Sem internet</b> — página aberta pela rede própria ZeloPlus (parte superior).</figcaption>
</figure>

- **④** Quando a rede salva não conecta ao ligar, o dispenser abre a rede própria
  `ZeloPlus` (Passo 4). No topo da página aparece o **aviso de sem internet**, com o
  motivo (aqui, a rede de casa não foi encontrada), o nome e a senha da rede própria, o
  botão **"Tentar conectar novamente"** e o link **"Trocar rede Wi-Fi"**. O restante da
  página é igual ao da imagem ②: alarmes, portas e histórico funcionam normalmente; só
  os avisos pelo Telegram aguardam a internet.

O visual segue três ideias, pensando em cuidadores e familiares com pouca
familiaridade com tecnologia:

- **Letras e botões grandes**, com bom contraste.
- **Uma cor por compartimento** — 1 **azul**, 2 **verde**, 3 **roxo** — no cartão do
  remédio, na dica de abastecimento, na reposição e no histórico.
- **Menos informação na tela:** remédios, paciente, cuidador e familiares aparecem
  **recolhidos** (só a faixa com o nome); um toque abre os detalhes.

**O que tem em cada bloco:**

| Bloco | Fechado mostra | Aberto mostra | Passo |
|---|---|---|---|
| **Aviso de sem internet** (só na rede própria) | Motivo, nome e senha da rede, "Tentar conectar novamente", "Trocar rede Wi-Fi" | — | 4 |
| **Aviso amarelo** (só se faltar algo) | Quem ainda não recebe avisos + "Configurar agora" | — | 7 |
| **Paciente** | Nome do paciente | Campo para editar o nome | 7 |
| **Remédios 1, 2 e 3** | Número, cor, remédio e horários | Nome, "Foto da caixa do remédio", horários (até 6), dica de onde colocar, "Esvaziar" | 7, 14, 20 |
| **Cuidador(a)** | Nome | Nome e celular | 7, 8 |
| **Familiares** | Nome de cada um | Nome, celular, "Remover"; "+ Cadastrar familiar" no fim | 7 |
| **Salvar alterações** | Botão azul grande | — | 8 |
| **Repor remédio** | Botão laranja | Escolha do remédio (por cor) e confirmação | 14 |
| **Histórico de doses** | % de adesão, contagem e adesão por remédio | "Ver últimas doses": tabela, planilha, apagar | 16 |
| **Trocar rede Wi-Fi** | Link (pede confirmação) | — | 4 |
| **Relógio DS3231** (rodapé) | "conectado" ou "não instalado" | — | 19 |
| **Avisos pelo Telegram** | "configurado ✓" ou "falta configurar" | Token, "Buscar IDs", ID de cada pessoa, teste | 15 |
| **Leitura da caixa por foto** | "configurada ✓" ou "falta a chave da IA" | Chave da API do Gemini, nome do modelo e como obter a chave | 20 |

---

# Parte B — Desenho técnico do gabinete

O gabinete do Zelo+ mede **210 × 130 × 100 mm** (comprimento × profundidade × altura).
Ele tem três compartimentos iguais na frente, uma área técnica na parte de trás (servos)
e uma faixa de eletrônica na base, onde ficam a tela, o botão e a luz de alerta.
Os componentes citados nesta parte são explicados em detalhe nas Partes
[C](#parte-c--o-código-passo-a-passo) (programa) e [E](#parte-e--uso-autônomo-sem-o-laptop)
(energia autônoma e relógio).

## B1. Desenho técnico dimensional

<figure markdown="1">
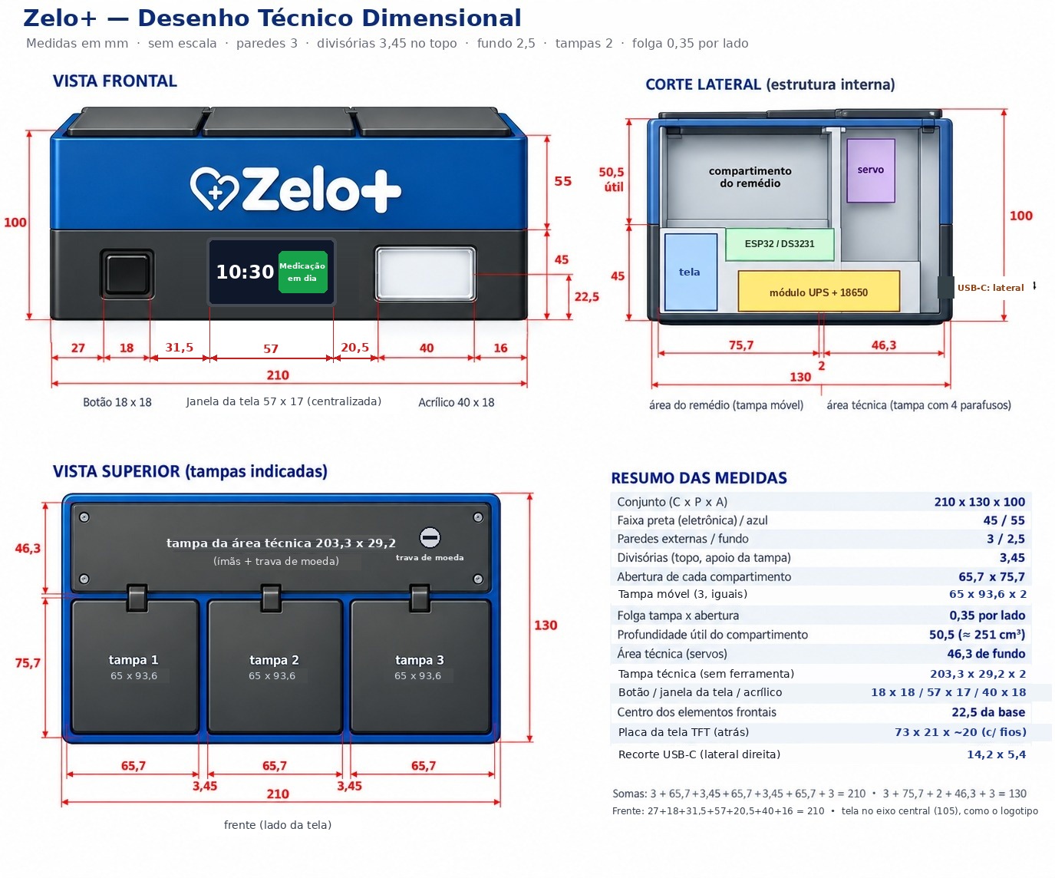
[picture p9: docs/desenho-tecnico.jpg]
Desenho técnico dimensional do gabinete

<figcaption><b>Desenho técnico dimensional do gabinete</b> — vista frontal, corte lateral, vista superior e resumo das medidas (em mm; vistas sem escala).</figcaption>
</figure>

As vistas também estão em escala no arquivo vetorial
[`docs/gabinete.svg`](docs/gabinete.svg) ([PNG](docs/gabinete.png)).

**Dimensões principais: 210 (C) × 130 (P) × 100 (A) mm.**

| Direção | Composição (mm) | Soma |
|---|---|---|
| Largura (vista superior) | 3 + **65,7** + 3,45 + **65,7** + 3,45 + **65,7** + 3 | **210** ✓ |
| Profundidade | 3 + **75,7** (compartimento) + 2 + **46,3** (área técnica) + 3 | **130** ✓ |
| Altura | 2,5 (fundo) + 42,5 (eletrônica) + 2,5 (piso) + **50,5** (compartimento) + 2 (tampa) | **100** ✓ |
| Frente | 27 + **18** (botão) + 31,5 + **57** (janela da tela) + 20,5 + **40** (acrílico) + 16 | **210** ✓ |

| Elemento | Medida (mm) |
|---|---|
| Faixa preta (eletrônica) / faixa azul (compartimentos) | 45 / 55 |
| Abertura de cada compartimento | 65,7 × 75,7 |
| Tampa móvel (3, iguais) | 65 × 93,6 × 2 (folga de 0,35 por lado na largura) |
| Eixo das dobradiças das tampas | 94,5 da frente e 1 abaixo do topo (13,8 atrás da divisória) |
| Divisórias entre compartimentos | 2 no corpo, **3,45 no topo** (apoio das tampas) |
| Profundidade útil do compartimento | 50,5 (≈ 251 cm³ cada) |
| Tampa da área técnica (**abre sem ferramenta**: 4 ímãs e trava de moeda) | 203,3 × 29,2 × 2 |
| Botão / janela da tela / acrílico | 18 × 18 / 57 × 17 / 40 × 18, centros a **22,5** da base |
| Centros horizontais (botão / tela / acrílico) | 36 / **105** / 174 |
| Placa da tela TFT (atrás do painel) | 73 × 21 × ~20 (com os conectores dos fios) |
| Área visível da tela | 55,2 × 14,8 (2,25" de diagonal, 284 × 76 pontos) |
| Recorte do USB-C (parede lateral direita) | 14,2 × 5,4, centro a 55 da frente e 15 da base |
| Furos de som do buzzer (parede lateral esquerda) | 9 × Ø 2,4 (3 × 3, passo 4), centro a 100 da frente e 20 da base |
| Fundo removível | 203,4 × 123,4 × 2,5, preso por 4 parafusos M3 |

## B2. Imagens do produto

<figure markdown="1">
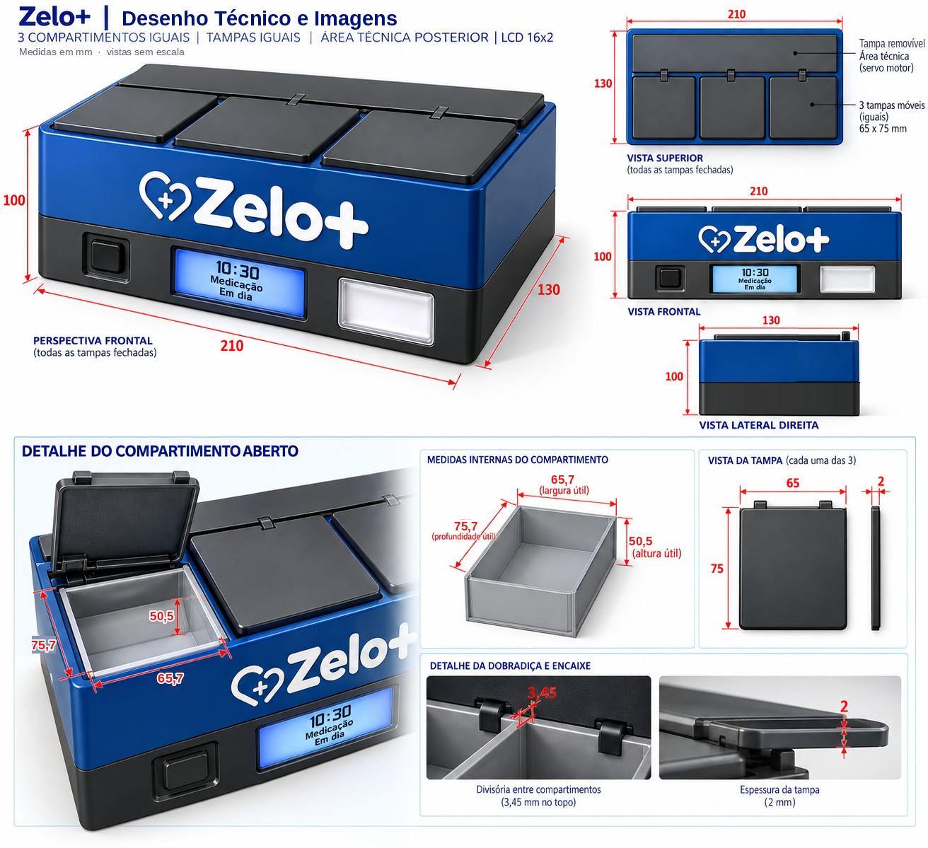
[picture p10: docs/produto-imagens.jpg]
Imagens do produto Zelo+

<figcaption><b>Imagens do produto</b> — perspectiva, vistas e detalhes do compartimento aberto, da dobradiça e do encaixe (medidas em mm; vistas sem escala).</figcaption>
</figure>

## B3. Critérios de projeto

- **Altura de 100 mm:**
  - A proporção fica **210 : 130 : 100** (≈ 2,1 : 1,3 : 1), com a altura em ~48 % da largura: perfil de caixa de mesa, estável e sem cara de "bloco".
  - A faixa preta de 45 mm acomoda a placa da tela (21 mm) com 12 mm de margem acima e abaixo.
  - Cada compartimento fica com **50,5 mm de profundidade útil** (~251 cm³), cerca de 8 vezes o volume de um mês de comprimidos (60 unidades ≈ 30 cm³). É raso o bastante para os dedos alcançarem o fundo.
  - Opcional: um fundo em rampa de 10–15° para a frente deixa os comprimidos mais perto da mão.
- **Frente simétrica:**
  - A janela da tela fica no **eixo central (105 mm)**, alinhada com o logotipo. Ela mede 57 × 17 mm: a área visível (55,2 × 14,8 mm) com cerca de 1 mm de folga de cada lado, para a borda da imagem não ficar escondida atrás do painel.
  - O botão (centro em 36 mm) e o acrílico (centro em 174 mm) ficam cada um no meio do seu lado, **à mesma distância do centro (69 mm)**. Assim os três elementos ficam equilibrados, mesmo com larguras diferentes.
- **Folga das tampas:** para a tampa de 65 mm de largura ter 0,35 mm de folga de cada lado, a abertura precisa medir 65,7 mm. Por isso as divisórias têm 3,45 mm no topo, onde as tampas se apoiam.
- **Dobradiça atrás da divisória:** o eixo fica 13,8 mm atrás da divisória do compartimento. Assim a alavanca do acionamento gira sem tocar a divisória quando a tampa abre a 90° (B5). Por isso a tampa mede 93,6 mm: cobre o compartimento, a divisória e a faixa da dobradiça.
- **Manutenção:** a tampa da área técnica abre **sem ferramenta** (ímãs e trava de moeda), com acesso aos servos e aos pinos das tampas. O **fundo removível** (4 parafusos M3) dá acesso à protoboard, ao ESP32 com o USB para atualizar o programa (E10), ao módulo UPS e à bateria.
- **Energia e som:** o conector USB-C de painel fica na **parede lateral direita**, ao lado do módulo UPS; os furos de som do buzzer ficam na **parede lateral esquerda**.
- **Emergência:** sem energia, cada tampa de compartimento se solta do servo pelo pino com argola, acessível pela tampa técnica (B5).

## B4. Onde fica cada componente

| Componente | Local no gabinete |
|---|---|
| Tela TFT 2,25" | Faixa preta, atrás da janela central (placa 73 × 21, ~20 de profundidade com os conectores) |
| Botão e LED (atrás do acrílico) | Faixa preta, nas laterais da tela |
| ESP32 na protoboard de 400 pontos | Berço da protoboard no fundo removível, sob os compartimentos (B6) |
| Relógio DS3231 | Berço próprio no fundo, sob a área técnica |
| Módulo UPS LX-2BUPS com as baterias 18650 (90 × 42 × 33) | Berço próprio no fundo, junto à lateral direita, com furos de ventilação embaixo |
| 3 servos SG90 | Área técnica, com o eixo paralelo ao da dobradiça, a 98,5 mm da frente e 73 mm da base (B5) |
| Conector USB-C de painel | Parede lateral direita, 15 mm acima da base, apoiado numa prateleira interna |
| Buzzer | Alojamento na parede lateral esquerda, atrás dos furos de som |
| Capacitor 1000 µF | Berço próprio no fundo, sob a área técnica |
| Pinos com argola (3) | Na ligação entre o braço de cada servo e a alavanca da tampa do compartimento (B5) |
| Ímãs e trava de moeda | Cantos e borda da tampa técnica (B5) |

## B5. Abertura de emergência sem energia

**Objetivo:** abrir qualquer compartimento **sem energia nenhuma** (sem rede e com a
bateria descarregada), sem forçar o servo. Parado, o SG90 segura a tampa pelas
engrenagens de plástico; abrir a tampa à força quebraria essas engrenagens.

<figure markdown="1">
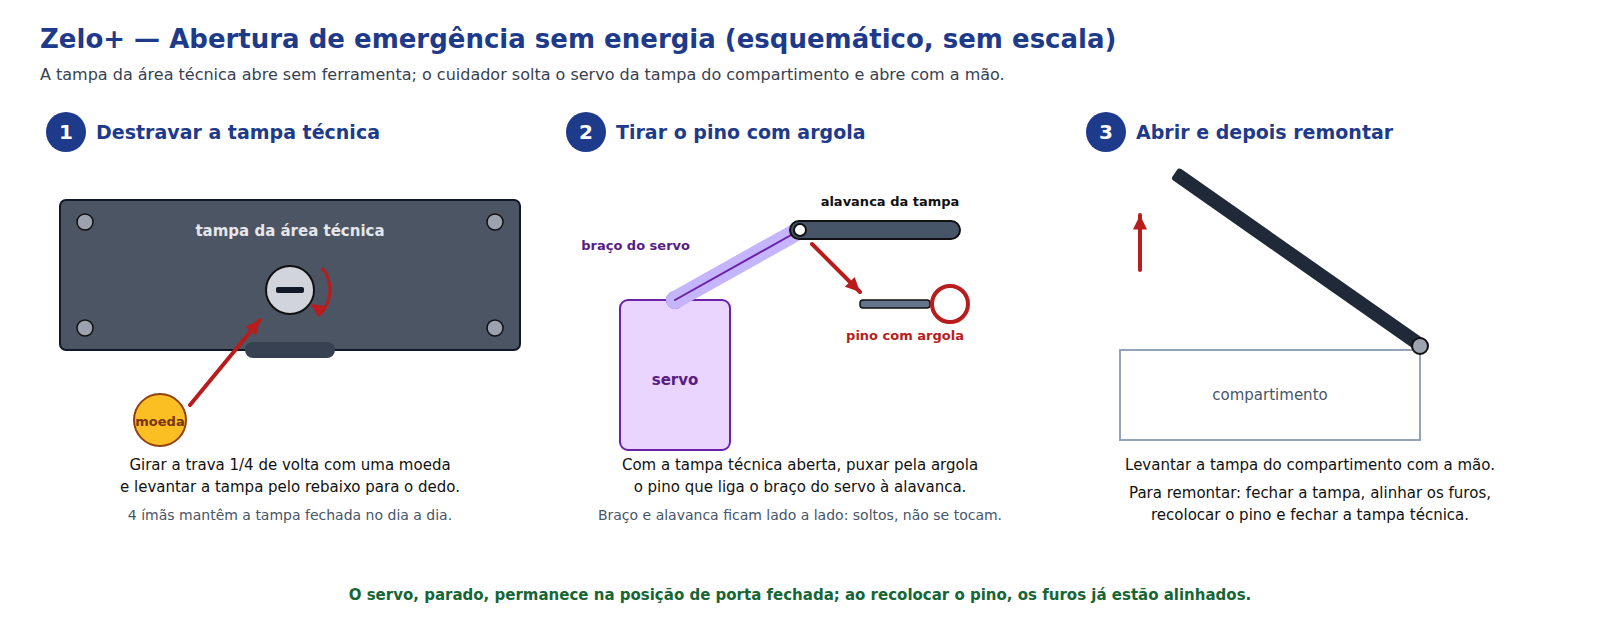
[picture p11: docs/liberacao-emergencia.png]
Abertura de emergência sem energia

<figcaption><b>Abertura de emergência sem energia</b> — destravar a tampa técnica com uma moeda, tirar o pino com argola que liga o servo à tampa do compartimento e abrir com a mão (esquemático, sem escala).</figcaption>
</figure>

**Solução:** a tampa da área técnica abre **sem ferramenta**, e cada servo se liga à
tampa do seu compartimento por um **pino com argola**, que se tira com os dedos.

| Elemento | Descrição |
|---|---|
| **Ímãs de fixação** | 4 pares de ímãs de neodímio de 6 × 2 mm, colados em rebaixos nos cantos da tampa técnica e nos apoios do gabinete. Mantêm a tampa fechada no dia a dia, sem parafusos. |
| **Trava de moeda** | Trava de 1/4 de volta com fenda, acionada com uma moeda. Impede que a tampa seja aberta por curiosidade ou por acidente. |
| **Rebaixo para o dedo** | Rebaixo na borda da tampa técnica para levantá-la depois de destravada. |
| **Pino com argola (3)** | Liga o braço de cada servo à alavanca da tampa do compartimento. Braço e alavanca ficam **lado a lado**, em planos diferentes: sem o pino, um não bloqueia o movimento do outro. |

**Peças do acionamento (impressão 3D):** o braço do servo e a tampa do compartimento
se ligam por um **pino que desliza num rasgo** da alavanca da tampa. O conjunto foi
dimensionado para o gabinete impresso: o servo trabalha com um curso curto, a alavanca
passa a 1,5 mm da divisória com a tampa aberta, e o braço não toca a tampa técnica.

<figure markdown="1">
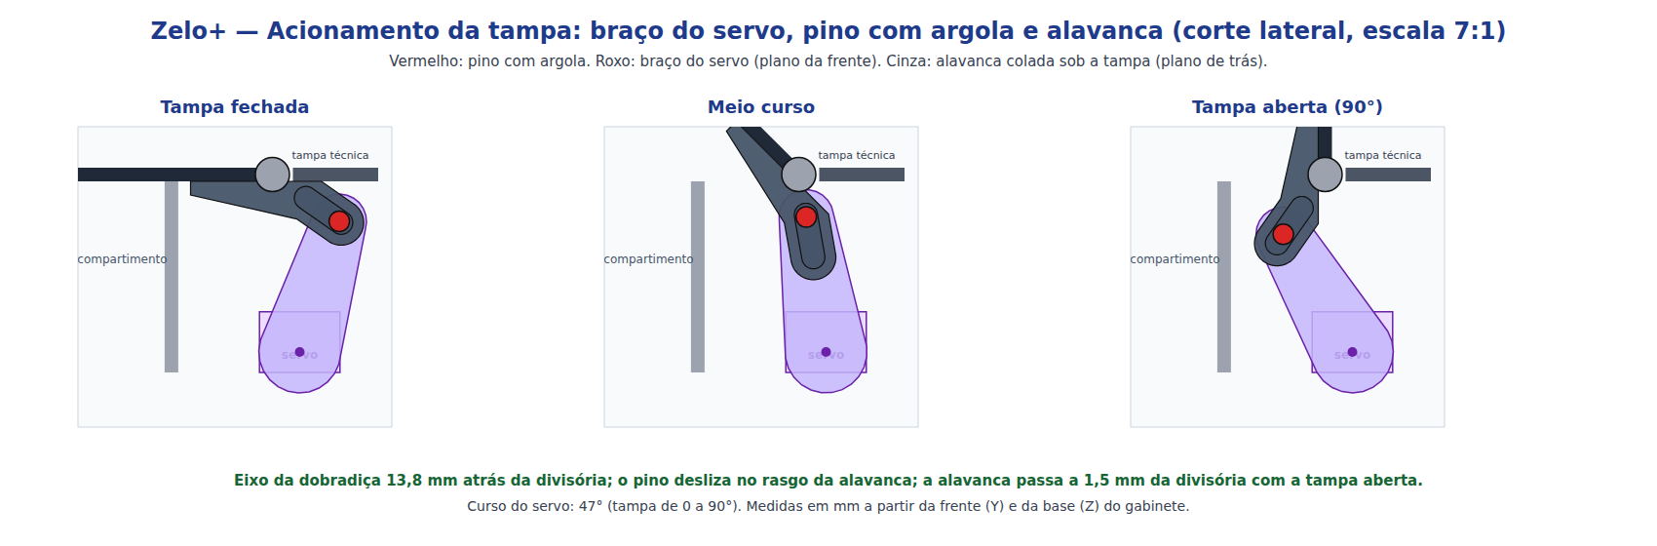
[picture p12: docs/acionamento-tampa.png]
Acionamento da tampa

<figcaption><b>Acionamento da tampa</b> — braço do servo, pino com argola e alavanca nas posições fechada, meio curso e aberta (corte lateral, escala 7:1).</figcaption>
</figure>

<figure markdown="1">
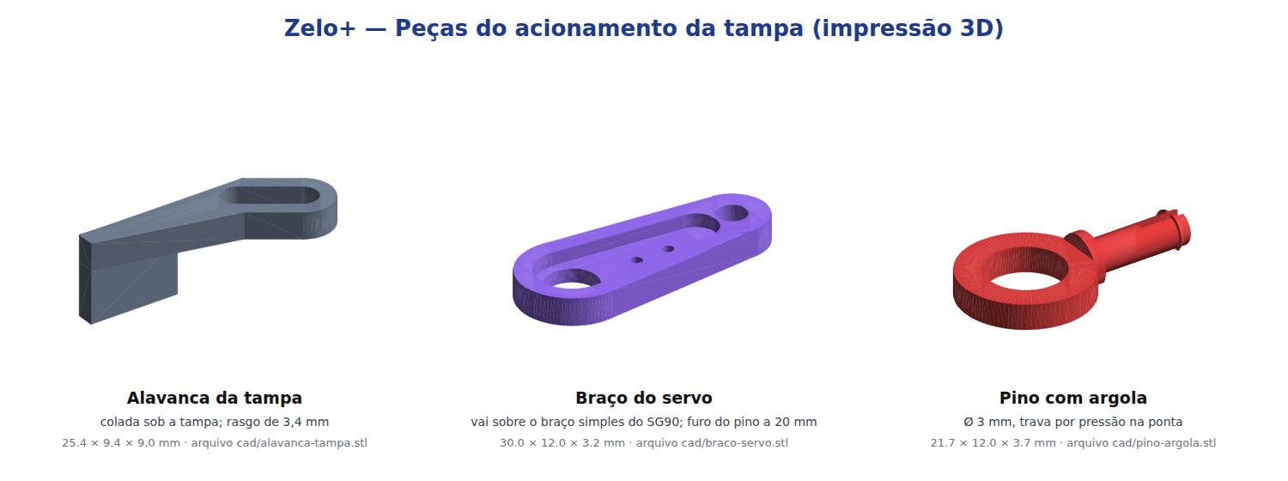
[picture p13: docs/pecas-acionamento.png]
Peças do acionamento

<figcaption><b>Peças do acionamento</b> — alavanca da tampa, braço do servo e pino com argola. Arquivos em <code>cad/</code>: STL para impressão e <code>zelo_acionamento.scad</code>, editável no OpenSCAD.</figcaption>
</figure>

| Posição | Medida (mm, a partir da frente e da base do gabinete) |
|---|---|
| Eixo da dobradiça da tampa | Y 94,5 · Z 99 (13,8 atrás da divisória) |
| Eixo do servo SG90 (paralelo ao da dobradiça) | Y 98,5 · Z 73 |
| Furo do pino no braço do servo | a 20 do eixo do servo |
| Rasgo da alavanca | de 6,0 a 12,3 do eixo da dobradiça, a 35° abaixo da horizontal com a tampa fechada |
| Curso do servo | 47° para a tampa ir de 0° a 90° |

| Peça | Impressão | Montagem |
|---|---|---|
| **Alavanca da tampa** | PETG, 100 % de preenchimento, camada de 0,16 mm; deitada sobre a face de colagem | Colada sob a tampa com cianoacrilato, de Y 82,5 a Y 92,7 (a face de colagem termina 1,8 mm à frente do eixo da dobradiça), perto de uma lateral da tampa e alinhada com o braço do servo |
| **Braço do servo** | PETG, 100 % de preenchimento, camada de 0,16 mm; com o rebaixo para cima | O braço simples original do SG90 encaixa no rebaixo; fixar com 2 parafusos M2 × 6 (ou cola) e o parafuso central do servo |
| **Pino com argola** | PETG, 100 % de preenchimento, camada de 0,12 mm; deitado, como no arquivo | Entra pelo lado da alavanca, atravessa o rasgo e o furo do braço e trava por pressão na ponta |

- **Ajuste do programa:** no gabinete impresso, o curso do servo é de 47°. Em
  `src/main.cpp`, `ANGULO_ABERTO` passa a ser `ANGULO_FECHADO` + 47 (ou − 47, conforme o
  lado em que o servo for montado). O braço deve ser encaixado no eixo do servo com a tampa
  fechada e o servo na posição `ANGULO_FECHADO`.
- **Folgas:** o rasgo e o furo do braço têm 3,4 mm para o pino de 3,0 mm. Se a
  impressora deixar os furos apertados, aumente `FURO` no arquivo `.scad` em 0,1 mm.

**Procedimento:**

1. Girar a trava 1/4 de volta com uma moeda e levantar a tampa técnica pelo rebaixo.
2. Puxar pela argola o pino do compartimento desejado.
3. Levantar a tampa do compartimento com a mão.
4. **Para remontar:** fechar a tampa do compartimento, alinhar o furo da alavanca com o
   do braço do servo (que, parado, permanece na posição de porta fechada), recolocar o
   pino e fechar a tampa técnica, girando a trava de volta.

**Critérios de projeto:**

- A trava de moeda mantém o controle das doses: o paciente não abre a área técnica por
  engano, e o procedimento fica com o cuidador.
- O sistema não usa energia nem depende do programa, e não tem peças de precisão.
- Se a energia voltar com um pino fora, o servo se move sem a tampa, sem dano; basta
  recolocar o pino.
- A tampa técnica sem parafusos também facilita a manutenção e a troca da bateria.

## B6. Modelo 3D do gabinete e impressão

O gabinete foi modelado em 3D com todos os suportes dos componentes do protótipo (com
protoboard). O modelo é gerado pelo programa [`cad/gabinete.py`](cad/gabinete.py), que
também confere, por computador, se alguma peça ou componente se encosta em outro, com a
tampa fechada e durante a abertura de 0° a 90° ([`cad/conferir_movimento.py`](cad/conferir_movimento.py)).
Nas duas conferências não houve nenhuma colisão.

<figure markdown="1">
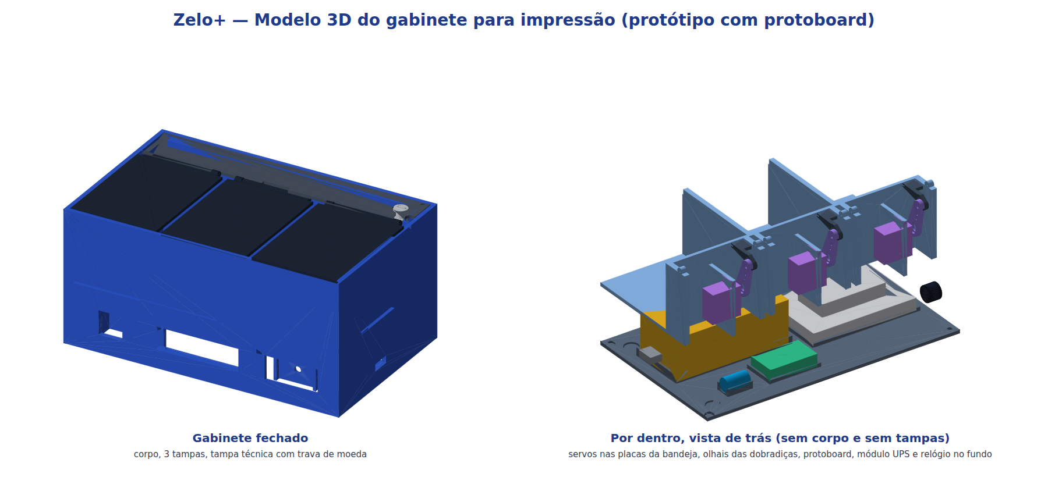
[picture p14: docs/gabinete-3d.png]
Modelo 3D do gabinete

<figcaption><b>Modelo 3D do gabinete</b> — à esquerda, fechado; à direita, vista de trás sem o corpo e sem as tampas, com os servos, a bandeja, o fundo e os componentes.</figcaption>
</figure>

**Peças para imprimir** (arquivos em `cad/gabinete/` e `cad/`):

| Peça | Qtd | Tamanho (mm) | Impressão | O que tem |
|---|---|---|---|---|
| **Corpo** (`corpo.stl`) | 1 | 210 × 130 × 100 | PLA, 20 % de preenchimento, 3 paredes; em pé, com suporte só sob os ressaltos internos e as colunas do fundo | Paredes; janelas da tela, do botão e do acrílico; berço do botão; suporte do LED; trilhos da tela; alojamento e furos de som do buzzer (lateral esquerda); recorte e prateleira do USB-C (lateral direita); apoios da bandeja, das tampas e da tampa técnica; rebaixos dos ímãs; colunas dos parafusos do fundo |
| **Bandeja** (`bandeja.stl`) | 1 | 203,4 × 104,7 × 56,5 | PLA, 20 %; com o piso na mesa, sem suporte | Piso e divisórias dos compartimentos; divisória da área técnica; 3 placas dos servos (janela para o corpo do SG90 e 2 furos para M2); olhais das dobradiças |
| **Fundo** (`fundo.stl`) | 1 | 203,4 × 123,4 × 8,5 | PLA, 20 %; deitado | Berços da protoboard (83 × 55), do módulo UPS (90 × 42) e do relógio (38 × 22); berço do capacitor; ventilação sob o UPS; rebaixos dos pés; furos dos 4 parafusos |
| **Tampa do compartimento** (`tampa-compartimento.stl`) | 3 | 65 × 93,7 × 5 | PLA, 100 %; com a face de cima na mesa e suporte só nas articulações | Placa da tampa, recortes dos olhais e 2 articulações |
| **Tampa técnica** (`tampa-tecnica.stl`) | 1 | 203,3 × 29,2 × 2 | PLA, 100 %; deitada | Rebaixos dos ímãs, furo da trava e rebaixo para o dedo |
| **Trava de moeda** (`trava-botao.stl` e `trava-lingueta.stl`) | 1 + 1 | 10 × 10 × 8,2 e 6 × 14 × 1,8 | PETG, 100 % | Botão com fenda para a moeda e lingueta encaixada no eixo quadrado |
| **Alavanca, braço do servo e pino com argola** | 3 de cada | ver B5 | PETG, 100 % | Acionamento das tampas (B5) |

**Ferragens e itens comprados:**

| Item | Qtd | Uso |
|---|---|---|
| Parafuso M3 × 8 autoatarraxante | 4 | Fundo |
| Parafuso M2 × 6 autoatarraxante | 12 | Abas dos servos (6) e braço do servo (6) |
| Filamento de 1,75 mm (pedaços de 9 mm) | 6 | Pinos das dobradiças, colados com uma gota de cola |
| Ímã de neodímio 6 × 2 mm | 8 | Tampa técnica (4) e apoios do corpo (4) |
| Pé de borracha adesivo de 10 mm | 4 | Fundo |
| Protoboard de 400 pontos (83 × 55 mm) | 1 | ESP32 e ligações, no berço do fundo |
| Placa de acrílico translúcido 42 × 20 × 2 mm | 1 | Janela do LED, colada no rebaixo |

**Ordem de montagem:**

1. **Corpo:** colar o acrílico no rebaixo da janela; encaixar a tela nos trilhos, com os
   pinos do lado do botão; colar o botão no berço, o LED no suporte, o buzzer no
   alojamento e o conector USB-C na prateleira (cola quente).
2. **Fundo:** colar a protoboard (fita dupla face que vem nela), o módulo UPS e o relógio
   nos berços; encaixar o capacitor; fazer as ligações (A2 e E3).
3. **Bandeja:** encaixar o corpo de cada servo na janela da sua placa e parafusar as abas; montar os
   braços e as alavancas (B5); descer a bandeja pelo topo do corpo até apoiar no ressalto
   a 45 mm da base, passando os fios dos servos para baixo.
4. **Tampas:** colar as alavancas sob as tampas; encaixar as articulações entre os olhais
   e passar os pinos de filamento; ligar braço e alavanca com o pino com argola.
5. **Fechamento:** fechar o fundo com os 4 parafusos; colar os ímãs; montar a trava de
   moeda na tampa técnica (botão por cima, lingueta por baixo).

O volume das peças modeladas é de cerca de 437 cm³, próximo da estimativa da G2
(443 cm³), usada no cálculo de custo do gabinete.

---

# Parte C — O código, passo a passo

## Passo 1 — Bibliotecas e pinos

**O que faz:** carrega as bibliotecas e dá nome aos pinos, para o resto do código
falar em `BUTTON_PIN` em vez de "5".

```cpp
#include <Arduino.h>
#include <WiFi.h>
#include <WiFiClientSecure.h>
#include <HTTPClient.h>
#include <ArduinoJson.h>
#include <WebServer.h>
#include <DNSServer.h>
#include <Preferences.h>
#include <time.h>
#include <Wire.h>
#include <LiquidCrystal_I2C.h>
#include <ESP32Servo.h>
#include <RTClib.h>
#include <esp_sntp.h>

#define BUZZER_PIN 15
#define LED_PIN 4
#define BUTTON_PIN 5
#define NUM_COMPARTIMENTOS 3
#define MAX_HORARIOS 6       // horarios por medicamento
#define MAX_FAMILIARES 5
#define MAX_HISTORICO 60
```

| Biblioteca | Para quê |
|---|---|
| `WiFi`, `WebServer`, `DNSServer` | Conectar à internet e servir a página de cadastro |
| `WiFiClientSecure`, `HTTPClient`, `ArduinoJson` | Falar com o Telegram (HTTPS + JSON) |
| `Preferences` | Memória permanente |
| `time.h` | Relógio (hora certa pela internet) |
| `Wire`, `LiquidCrystal_I2C` | LCD pelo barramento I2C |
| `ESP32Servo` | Controlar os servos |
| `RTClib`, `esp_sntp.h` | Relógio DS3231 e aviso de "hora acertada pela internet" ([Passo 19](#passo-19--relógio-ds3231-próxima-etapa)) |

Os pinos e ângulos de cada servo ficam em **vetores** (listas), um item por
compartimento:

```cpp
const int PINOS_SERVO[NUM_COMPARTIMENTOS] = {13, 14, 27};
// Angulos de cada porta (ajuste aqui se algum mecanismo precisar de outro valor).
const int ANGULO_FECHADO[NUM_COMPARTIMENTOS] = {0, 0, 0};
const int ANGULO_ABERTO[NUM_COMPARTIMENTOS] = {90, 90, 90};
```

> `PINOS_SERVO[0]` é o compartimento **1** (em programação, a contagem começa
> em zero). Esse detalhe aparece no código inteiro: índice `c` = compartimento `c + 1`.

Por fim, os **objetos** que representam cada peça:

```cpp
LiquidCrystal_I2C lcd(0x27, 16, 2);
Servo servos[NUM_COMPARTIMENTOS];
WebServer server(80);
DNSServer dnsServer;
Preferences preferences;
Preferences prefsCadastro;
Preferences prefsHistorico;
```

- `lcd(0x27, 16, 2)`: LCD no endereço I2C `0x27`, 16 colunas, 2 linhas.
- `server(80)`: servidor web na porta 80 (a porta padrão dos navegadores).
- Três `Preferences`, uma para cada "gaveta" da memória: Wi-Fi, cadastro e histórico.

## Passo 2 — Estruturas de dados

**O que faz:** define como o programa guarda um **contato** e um **medicamento**.

```cpp
struct Contato {
  String nome;
  String telefone;
  String chatId;
};

// Medicamento guardado num compartimento fixo (indice 0..2 = compartimento 1..3).
struct Medicamento {
  String nome;
  int totalHorarios = 0;
  int hora[MAX_HORARIOS];
  int minuto[MAX_HORARIOS];
  bool jaDisparado[MAX_HORARIOS];
};

String nomePaciente = "";
Medicamento medicamentos[NUM_COMPARTIMENTOS];
Contato cuidador;
Contato familiares[MAX_FAMILIARES];
```

- `struct` agrupa várias informações sob um nome só — como uma ficha.
- `medicamentos[3]`: a **posição no vetor é o compartimento**. O remédio em
  `medicamentos[1]` está sempre no compartimento 2. É isso que "prende" cada
  remédio ao seu compartimento.
- `jaDisparado[]`: impede que o mesmo horário toque duas vezes no mesmo minuto.
- `chatId`: número que o Telegram usa para identificar cada pessoa (Passo 15).

Os **estados** da máquina de estados:

```cpp
enum Estado { AGUARDANDO, TOCANDO, PORTA_ABERTA_ESTADO, ABASTECENDO };
Estado estadoAtual = AGUARDANDO;
```

E as variáveis da **dose atual** (usam máscara de bits, conceito 4):

```cpp
uint8_t doseMascara = 0;
String horarioDose = "";
String nomesDose = "";
unsigned long alarmeIniciadoEm = 0;
int nivelAvisoEnviado = 0;   // 0 = nenhum, 1 = cuidador avisado, 2 = todos alertados
bool dosePendente = false;   // alarme terminou sem acesso; botao ainda abre os compartimentos
```

Duas funções pequenas ajudam a trabalhar com isso:

```cpp
bool temBit(uint8_t mascara, int i) {
  return (mascara >> i) & 1;
}

bool medicamentoAtivo(int c) {
  return medicamentos[c].nome != "" && medicamentos[c].totalHorarios > 0;
}
```

- `temBit(5, 0)` → verdadeiro (compartimento 1 está na máscara `101`).
- `medicamentoAtivo(c)`: um compartimento só conta se tiver nome **e** horário.

## Passo 3 — `setup()`: ligando tudo

**O que faz:** roda uma vez ao ligar. Configura pinos, posiciona as portas,
liga o LCD, **lê a memória** e tenta conectar no Wi-Fi.

```cpp
  pinMode(BUZZER_PIN, OUTPUT);
  pinMode(LED_PIN, OUTPUT);
  pinMode(BUTTON_PIN, INPUT_PULLUP);
  digitalWrite(BUZZER_PIN, LOW);
  digitalWrite(LED_PIN, LOW);

  for (int c = 0; c < NUM_COMPARTIMENTOS; c++) {
    servos[c].setTimerWidth(RESOLUCAO_SERVO);  // precisa vir antes do attach
    servos[c].attach(PINOS_SERVO[c], PULSO_0_GRAU, PULSO_180_GRAUS);
    servos[c].write(ANGULO_FECHADO[c]);
    delay(500);
  }
```

- `OUTPUT`: o ESP32 **manda** energia no pino (buzzer, LED).
- `INPUT_PULLUP`: o pino fica "puxado" para 3,3 V por um resistor **interno**. Quando
  o botão é apertado, ele liga o pino ao GND e a leitura vira `LOW`. Por isso o botão
  não precisa de resistor externo, e "apertado" é `digitalRead(BUTTON_PIN) == LOW`.
- O `for` percorre os 3 servos, liga cada um no seu pino e fecha a porta, **um de cada
  vez**, com meio segundo de intervalo. Ao receber o primeiro sinal, o servo corre para a
  posição fechada e puxa um pico de corrente; os três juntos, na mesma fonte de 5 V do
  ESP32, derrubariam a tensão e a placa reiniciaria.

Em seguida liga o LCD e **procura o relógio DS3231** (se ele não estiver instalado, o
programa só anota isso e segue — detalhes no [Passo 19](#passo-19--relógio-ds3231-próxima-etapa)):

```cpp
  lcd.init();
  lcd.backlight();
  lcd.print("Iniciando...");

  iniciarRelogioRTC();
```

Depois, carrega a memória e decide o modo de Wi-Fi:

```cpp
  prefsCadastro.begin("cadastro", false);
  carregarCadastro();
  prefsHistorico.begin("historico", false);
  carregarHistorico();

  preferences.begin("wifi", false);
  String ssidSalvo = preferences.getString("ssid", "");
  String senhaSalva = preferences.getString("pass", "");
```

```cpp
  if (WiFi.status() == WL_CONNECTED) {
    iniciarModoNormal();
  } else if (ssidSalvo != "") {
    // Rede salva fora do ar, fora de alcance ou com senha recusada: o dispenser
    // abre a rede propria e continua funcionando (hora pelo DS3231 ou pelo celular).
    iniciarModoLocal(descreverFalhaWiFi(WiFi.status()));
  } else {
    iniciarModoConfig();
  }
```

- Se existe rede salva e a conexão funciona → **modo normal** (Passo 5).
- Se existe rede salva, mas ela **não conectou** (fora do ar, fora de alcance, só em
  5 GHz ou com a senha recusada) → **rede própria automática**: o dispenser abre a rede
  `ZeloPlus` e continua funcionando sem internet (Passo 4).
- Se **nenhuma rede foi salva** → **modo de configuração** (Passo 4).

## Passo 4 — Wi-Fi sem senha no código (captive portal)

**O que faz:** quando a placa não sabe em qual Wi-Fi entrar, ela **cria a sua
própria rede** chamada `ZeloPlus-Config`. Ao conectar o celular nela, a página de
configuração abre sozinha (igual ao Wi-Fi de aeroporto).

```cpp
void iniciarModoConfig() {
  modoConfig = true;

  WiFi.disconnect();  // para de tentar a rede salva, senao a busca de redes falha
  WiFi.mode(WIFI_AP_STA);
  WiFi.softAPConfig(apIP, apIP, IPAddress(255, 255, 255, 0));
  WiFi.softAP("ZeloPlus-Config");

  dnsServer.start(DNS_PORT, "*", apIP);
```

- `WiFi.disconnect()`: interrompe as tentativas de conexão à rede salva (por exemplo,
  a rede de casa quando o dispenser está em outro local). Sem isso, a busca de redes
  falharia e a lista da página viria vazia.
- `softAP`: transforma o ESP32 em um **ponto de acesso** (roteador).
- `dnsServer.start(..., "*", apIP)`: responde **qualquer** endereço digitado com o IP
  da placa (`192.168.4.1`). É esse "truque" que faz o celular abrir a página sozinho.

A página lista as redes encontradas (o ESP32 opera apenas em **2,4 GHz**; redes de
5 GHz não aparecem) e oferece um campo para digitar o nome da rede, útil para redes
ocultas. Quando o cuidador escolhe a rede e digita a senha, a placa testa e, se der
certo, **grava** e reinicia:

```cpp
  if (WiFi.status() == WL_CONNECTED) {
    preferences.putString("ssid", ssid);
    preferences.putString("pass", senha);
```

```cpp
    delay(3000);
    ESP.restart();
```

Da próxima vez que ligar, o `setup()` encontra a rede salva e vai direto para o
modo normal. O link "Trocar rede Wi-Fi" da página apaga essa rede
(`preferences.remove("ssid")`) e reinicia no modo de configuração. Manter o
**botão apertado ao ligar** também leva direto ao modo de configuração, sem tentar a
rede salva.

**Uso sem internet (rede própria).** Em locais sem internet, como uma sala de aula ou
de apresentação, a página de configuração oferece o botão **"Usar sem internet"**. O
dispenser passa a funcionar na própria rede `ZeloPlus-Config`, no endereço
`http://192.168.4.1`, e acerta o relógio com a hora do aparelho conectado:

```cpp
void handleModoLocal() {
  uint32_t segundos = strtoul(server.arg("epoch").c_str(), nullptr, 10);
  if (segundos >= HORA_MINIMA_VALIDA) {
    struct timeval agora = { (time_t)segundos, 0 };
    settimeofday(&agora, nullptr);
    if (rtcPresente) rtc.adjust(DateTime(segundos));
  }
```

- `epoch`: a hora do celular, em segundos, preenchida pelo navegador
  (`Date.now()`) no momento do toque no botão.
- `settimeofday`: acerta o relógio interno do ESP32; se houver DS3231, ele também é
  acertado.

Nesse modo funcionam a página, o cadastro, os alarmes, as portas, o histórico e a
reposição. Os avisos pelo **Telegram** não são enviados, pois dependem de internet.
Sem o DS3231, a hora se perde ao desligar o dispenser e precisa ser informada de novo
pelo mesmo botão.

**Rede própria automática.** Quando já existe uma rede salva, mas ela não conecta ao
ligar, o dispenser não para: ele abre sozinho a rede **`ZeloPlus`**, protegida pela
senha **`zelo1234`**, e segue no modo normal. O motivo da falha fica registrado para o
aviso da página:

```cpp
String descreverFalhaWiFi(wl_status_t situacao) {
  if (situacao == WL_NO_SSID_AVAIL) {
    return "a rede " + redeSalva + " não foi encontrada (o dispenser só enxerga redes de 2,4 GHz)";
  }
  if (situacao == WL_CONNECT_FAILED) {
    return "a rede " + redeSalva + " recusou a conexão (confira a senha)";
  }
  return "não foi possível conectar à rede " + redeSalva;
}
```

```cpp
void iniciarModoLocal(const String& motivo) {
  modoLocal = true;
  nomeRedeLocal = NOME_REDE_LOCAL;
  motivoSemInternet = motivo;
  WiFi.setAutoReconnect(false); // novas tentativas so no horario certo (manterRedeLocal)
  WiFi.disconnect();
  WiFi.mode(WIFI_AP_STA);
  WiFi.softAPConfig(apIP, apIP, IPAddress(255, 255, 255, 0));
  WiFi.softAP(NOME_REDE_LOCAL, SENHA_REDE_LOCAL);
  dnsServer.start(DNS_PORT, "*", apIP);
  registrarPortalCativo();
  Serial.println("Sem internet: " + motivo);
  iniciarModoNormal();
}
```

- O LCD mostra `Rede ZeloPlus` / `senha zelo1234` e, em seguida, `Pagina:` /
  `192.168.4.1`. Ao conectar o celular à rede `ZeloPlus`, a página do dispenser abre
  sozinha.
- No topo da página aparece um **aviso** com o motivo, o nome e a senha da rede e o
  botão **"Tentar conectar novamente"**, além do link "Trocar rede Wi-Fi".
- Se o dispenser não souber a hora (sem internet e sem DS3231), a página envia a hora
  do celular assim que é aberta (rota `/acertar-hora`), e os alarmes passam a
  funcionar.

**Novas tentativas.** Na rede própria, o dispenser tenta a rede salva **a cada 10
minutos**, sem travar o programa:

```cpp
void manterRedeLocal() {
  static unsigned long ultimaTentativaLocal = millis();
  if (tentandoRede) {
    wl_status_t situacao = WiFi.status();
    if (situacao == WL_CONNECTED) {
      sairModoLocal();
      return;
    }
    if (millis() - tentativaIniciadaEm < DURACAO_TENTATIVA) return;
    tentandoRede = false;
    motivoSemInternet = descreverFalhaWiFi(situacao);
    WiFi.disconnect(); // so a conexao com a rede salva; a rede propria continua
    ultimaTentativaLocal = millis();
    Serial.println("Ainda sem internet: " + motivoSemInternet);
    return;
  }
  if (redeSalva == "") return;
  if (millis() - ultimaTentativaLocal < INTERVALO_NOVA_TENTATIVA) return;
  if (WiFi.softAPgetStationNum() > 0) return;
  iniciarTentativaRede();
}
```

- `softAPgetStationNum()`: número de aparelhos conectados à rede `ZeloPlus`. A tentativa
  automática espera ninguém estar conectado, porque o ESP32 tem um único rádio e, ao
  procurar a rede salva, derrubaria a conexão de quem está usando a página.
- O botão **"Tentar conectar novamente"** faz a mesma tentativa na hora, avisando antes
  que a conexão com a rede `ZeloPlus` pode cair.
- Quando a rede salva conecta (`sairModoLocal`), a rede `ZeloPlus` é desligada, o LCD
  mostra o novo IP e o Telegram volta a funcionar.

## Passo 5 — Modo normal: relógio pela internet e rotas da página

**O que faz:** acerta o relógio pela internet, mostra o IP no LCD e diz ao servidor
qual função atende cada endereço da página.

```cpp
const char* ntpServer = "pool.ntp.org";
const long gmtOffset_sec = -10800; // Brasília (GMT-3)
const int daylightOffset_sec = 0;
```

```cpp
  sntp_set_time_sync_notification_cb(aoSincronizarNTP);
  configTime(gmtOffset_sec, daylightOffset_sec, ntpServer);
```

- **NTP** é um serviço da internet que informa a hora exata. `-10800` segundos =
  3 horas a menos que o horário mundial (UTC) = horário de Brasília.
- A primeira linha pede ao NTP para **avisar** (chamando `aoSincronizarNTP`) toda vez
  que acertar a hora. É esse aviso que faz o programa gravar a hora no DS3231
  (Passo 19).

Em seguida o LCD mostra o **IP** da página ou, na rede própria (Passo 4), o nome e a
senha da rede e o endereço `192.168.4.1`:

```cpp
  lcd.clear();
  if (modoLocal) {
    // Visor: nome e senha da rede propria, depois o endereco da pagina.
    escreverLinhaLCD(0, "Rede " + nomeRedeLocal);
    escreverLinhaLCD(1, nomeRedeLocal == NOME_REDE_LOCAL ? "senha " + String(SENHA_REDE_LOCAL) : "sem senha");
    delay(4000);
    escreverLinhaLCD(0, "Pagina:");
    escreverLinhaLCD(1, "192.168.4.1");
    Serial.println("Sem internet: rede " + nomeRedeLocal + ", acesse http://192.168.4.1");
  } else {
    lcd.print("IP do sistema:");
    lcd.setCursor(0, 1);
    lcd.print(WiFi.localIP());
    Serial.print("Acesse: http://");
    Serial.println(WiFi.localIP());
  }
```

As **rotas** ligam um endereço a uma função:

```cpp
  server.on("/", handleRoot);
  server.on("/salvar", HTTP_POST, handleSalvar);
  server.on("/abrir-manual", HTTP_POST, handleAbrirManual);
  server.on("/esvaziar", HTTP_POST, handleEsvaziar);
  server.on("/testar-mensagens", HTTP_POST, handleTestarMensagens);
  server.on("/telegram-ids", HTTP_POST, handleTelegramIds);
  server.on("/ler-caixa", HTTP_POST, handleLerCaixa, receberFoto);
  server.on("/historico.csv", handleHistoricoCSV);
  server.on("/limpar-historico", HTTP_POST, handleLimparHistorico);
  server.on("/trocar-wifi", handleTrocarWifi);
  server.on("/tentar-wifi", HTTP_POST, handleTentarWifi);
  server.on("/acertar-hora", HTTP_POST, handleAcertarHora);
  if (!servidorNoAr) {
    server.begin();
    servidorNoAr = true;
  }
```

| Endereço | O que acontece |
|---|---|
| `/` | Mostra a página de cadastro (Passo 7) |
| `/salvar` | Recebe o formulário e grava (Passo 8) |
| `/abrir-manual` | Abre um compartimento para reposição (Passo 14) |
| `/esvaziar` | Esvazia um compartimento (Passo 14) |
| `/testar-mensagens`, `/telegram-ids` | Telegram (Passo 15) |
| `/ler-caixa` | Leitura da caixa do remédio por foto (Passo 20) |
| `/tentar-wifi`, `/acertar-hora`, `/trocar-wifi` | Rede própria: nova tentativa, hora pelo celular e troca de rede (Passo 4) |
| `/historico.csv`, `/limpar-historico` | Histórico (Passo 16) |

## Passo 6 — Memória permanente (Preferences)

**O que faz:** grava e lê o cadastro na memória flash, para ele sobreviver a
quedas de energia.

Cada compartimento tem suas chaves: `m0_` (compartimento 1), `m1_`, `m2_`.

```cpp
void salvarMedicamento(int c) {
  const Medicamento& m = medicamentos[c];
  String p = prefixoMedicamento(c);
  uint8_t horas[MAX_HORARIOS];
  uint8_t minutos[MAX_HORARIOS];
  for (int i = 0; i < m.totalHorarios; i++) {
    horas[i] = (uint8_t)m.hora[i];
    minutos[i] = (uint8_t)m.minuto[i];
  }
  prefsCadastro.putString((p + "_nome").c_str(), m.nome);
  prefsCadastro.putUChar((p + "_tot").c_str(), (uint8_t)m.totalHorarios);
  if (m.totalHorarios > 0) {
    prefsCadastro.putBytes((p + "_hr").c_str(), horas, m.totalHorarios);
    prefsCadastro.putBytes((p + "_mn").c_str(), minutos, m.totalHorarios);
  }
}
```

- `putString` grava texto; `putUChar` grava um número pequeno (0–255);
  `putBytes` grava uma lista de bytes (as horas e os minutos).
- Exemplo do que fica gravado para "Losartana às 08:00 e 20:00" no compartimento 1:
  `m0_nome = "Losartana"`, `m0_tot = 2`, `m0_hr = [8, 20]`, `m0_mn = [0, 0]`.

Na leitura, o programa **confere** se os dados fazem sentido antes de usar:

```cpp
  int validos = 0;
  for (int i = 0; i < total; i++) {
    if (horas[i] > 23 || minutos[i] > 59) continue;
    horaDestino[validos] = horas[i];
    minutoDestino[validos] = minutos[i];
    disparadoDestino[validos] = false;
    validos++;
  }
  return validos;
```

**Migração:** a versão anterior (um compartimento só) gravava o remédio em chaves
diferentes. Na primeira vez que a versão nova liga, ela copia esse remédio para o
compartimento 1 e apaga as chaves antigas:

```cpp
void migrarCadastroAntigo() {
  if (prefsCadastro.isKey("m0_nome") || !prefsCadastro.isKey("remedio")) return;

  Medicamento& m = medicamentos[0];
  m.nome = prefsCadastro.getString("remedio", "");
  m.nome.trim();
  m.totalHorarios = lerHorarios("total", "horas", "minutos", m.hora, m.minuto, m.jaDisparado);
  salvarMedicamento(0);
```

- `trim()` tira espaços do começo e do fim do nome. Versões antigas podiam gravar
  "Losartana " (com espaço), e sem essa limpeza o sistema achava que o remédio tinha
  mudado e abria o compartimento sem necessidade.

## Passo 7 — A página de cadastro

**O que faz:** quando o navegador abre o IP da placa, a função `handleRoot()`
**monta o HTML** (o texto da página) e envia. O visual foi pensado para quem tem
pouca familiaridade com tecnologia: **letras e botões grandes**, **uma cor por
compartimento** e **blocos recolhidos** — só o essencial aparece; um toque abre os
detalhes.

**1) Uma cor por compartimento.** Três listas guardam a cor de cada um (use
etiquetas das mesmas cores na caixa do dispenser):

```cpp
const char* COR_COMPARTIMENTO[NUM_COMPARTIMENTOS] = {"#2563eb", "#16a34a", "#9333ea"};
const char* FUNDO_COMPARTIMENTO[NUM_COMPARTIMENTOS] = {"#eff6ff", "#f0fdf4", "#faf5ff"};
const char* NOME_COR[NUM_COMPARTIMENTOS] = {"azul", "verde", "roxo"};
```

**2) Blocos recolhidos.** O HTML tem um elemento pronto para isso: `<details>`
mostra só o `<summary>` (a "faixa") e esconde o resto até alguém tocar. Cada
compartimento é um `<details>` com a sua cor; na faixa aparecem número, remédio e
horários:

```cpp
  String html = "<details class='comp' style='--cor:" + String(COR_COMPARTIMENTO[c]) + ";--fundo:" +
                String(FUNDO_COMPARTIMENTO[c]) + "'" + (aberto ? " open" : "") + "><summary>";
  html += marcaCompartimento(c, 44);
  if (medicamentoAtivo(c)) {
    html += "<span><b>" + escaparHTML(m.nome) + "</b><small>Compartimento " + n + " (" + NOME_COR[c] + ") &middot; " +
            horariosTexto(m) + "</small></span>";
  } else {
    html += "<span><b>Compartimento " + n + "</b><small>" + NOME_COR[c] + " &middot; vazio &middot; toque para cadastrar</small></span>";
  }
```

- `--cor` e `--fundo` são **variáveis de CSS**: o mesmo estilo (`.comp`) pinta a
  borda e o fundo de cada cartão com a cor do seu compartimento.
- `marcaCompartimento()` desenha a bolinha colorida com o número (ela também aparece
  na reposição e no histórico).
- O compartimento 1 só vem aberto no primeiro uso (nenhum remédio cadastrado).

Dentro do cartão, a **dica de onde colocar o remédio** repete número e cor:

```cpp
  html += "&#128230; Coloque <b>" + escaparHTML(m.nome) + "</b> no <b>compartimento " + n + " (" + NOME_COR[c] + ")</b></div>";
```

Resultado: 📦 Coloque **Losartana** no **compartimento 1 (azul)**. A dica muda
**enquanto o cuidador digita**, com um pequeno código JavaScript que roda no
navegador:

```cpp
  html += "function atualizarDica(c) {";
  html += "  var nome = document.getElementById('m' + c + '_nome').value.trim();";
  html += "  var dica = document.getElementById('dica-' + c);";
  html += "  dica.style.display = nome ? 'block' : 'none';";
```

**3) Pessoas recolhidas.** Cuidador e familiares aparecem **só pelo nome**; tocando,
abrem nome e celular. O familiar novo fica atrás do botão "+ Cadastrar familiar":

```cpp
  html += "<summary><span style='font-size:28px'>" + String(icone) + "</span><span><b>";
  html += contato.nome != "" ? escaparHTML(contato.nome) : String(familiar ? "Novo familiar" : "Cuidador(a)");
```

Cada familiar ocupa uma "vaga" (`fam0` a `fam4`). Ao cadastrar, o navegador procura a
primeira vaga livre; ao remover, apaga o ID do Telegram daquela vaga — assim um
familiar novo nunca herda o ID de quem saiu:

```cpp
  html += "    if (usados.indexOf('fam' + i) >= 0) continue;";
  html += "    var modelo = document.getElementById('modelo-familiar').innerHTML.split('famX').join('fam' + i);";
```

**4) Telegram só quando precisa.** O bloco do Telegram fica no **fim da página**,
depois de "Trocar rede Wi-Fi". Ele só aparece **aberto** (e com um aviso no topo)
enquanto faltar o token ou o ID de alguém — por exemplo, logo depois de cadastrar um
familiar novo. Configurado, vira uma linha discreta "configurado ✓":

```cpp
bool telegramPendente(String* faltando) {
  bool pendente = (tokenTelegram == "");
  if (cuidador.nome != "" && cuidador.chatId == "") {
    pendente = true;
```

Os campos desse bloco ficam **fora** do formulário principal, mas são enviados junto
graças ao atributo `form='cadastro'`:

```cpp
  html += "</label><input type='text' inputmode='numeric' form='cadastro' name='" + prefixo + "_chat' id='chat-" + prefixo +
```

**5) Troca de remédio num compartimento já usado** — antes de enviar, o navegador
compara o nome antigo (guardado em `data-original`) com o novo e pede confirmação:

```cpp
  html += "    if (antigo && novo && antigo.toLowerCase() != novo.toLowerCase()) {";
  html += "      if (!confirm('O compartimento ' + (c + 1) + ' (' + CORES[c] + ') tinha ' + antigo + '. Retire todos os comprimidos antigos antes de colocar ' + novo + '. Confirmar troca?')) return false;";
```

> **Segurança:** todo texto digitado passa por `escaparHTML()` antes de entrar na
> página. Assim, um nome como `D'Ávila` ou `<b>` não quebra o HTML.
>
> ```cpp
> case '<': saida += "&lt;"; break;
> ```

## Passo 8 — Salvando o cadastro

**O que faz:** `handleSalvar()` recebe o formulário, **valida** tudo e só então grava.

**Como a página envia o cadastro:** o botão **Salvar** não usa o envio clássico de
formulário. A página envia os dados com `fetch`, como nos demais comandos (repor,
esvaziar, Telegram). A página do dispenser é servida por `http://` na rede local, e o
envio clássico por `http://` faz o navegador exibir o aviso "as informações que você
está prestes a enviar não estão protegidas". Com `fetch`, esse aviso não aparece:

```cpp
  html += "function enviarCadastro(e) {";
  html += "  e.preventDefault();";
  html += "  if (!confirmarTrocas()) return false;";
  html += "  var form = document.getElementById('cadastro');";
  html += "  fetch('/salvar', {method:'POST', body: new URLSearchParams(new FormData(form))})";
  html += "    .then(function(r){ if (r.ok) { location.href = '/'; return; } return r.text().then(function(t){ alert(t); }); })";
  html += "    .catch(function(){ alert('Não foi possível salvar. Verifique a conexão com o dispenser.'); });";
  html += "  return false;";
  html += "}";
```

- `e.preventDefault()` cancela o envio clássico; `FormData` junta os mesmos campos
  que o formulário enviaria (inclusive os que ficam fora dele, ligados por
  `form='cadastro'`).
- Se o dispenser aceitar (resposta de sucesso), a página é recarregada com os dados
  novos; se recusar (por exemplo, cuidador sem celular), a mensagem aparece num alerta
  e nada do que foi digitado se perde.

1. **Cuidador é obrigatório:**

```cpp
  if (novoCuidador.nome == "" || novoCuidador.telefone == "") {
    server.send(400, "text/plain; charset=utf-8", "O cuidador é obrigatório: preencha nome e celular.");
    return;
  }
```

2. **Cada remédio precisa de horário, e ao menos um remédio precisa existir:**

```cpp
    if (novos[c].nome != "" && novos[c].totalHorarios == 0) {
```

```cpp
  if (ativos == 0) {
    server.send(400, "text/plain; charset=utf-8", "Cadastre ao menos um medicamento. Volte e corrija.");
    return;
  }
```

3. **Descobre quais compartimentos receberam remédio novo** e os coloca numa
   **fila de abastecimento** (máscara de bits):

```cpp
    if (novo != "" && novo != antigo) filaAbastecimento |= (uint8_t)(1 << c);
    if (novo == "") filaAbastecimento &= (uint8_t)~(1 << c);
    medicamentos[c] = novos[c];
```

- `|= (1 << c)` **liga** o bit do compartimento `c` ("este precisa abrir").
- `&= ~(1 << c)` **desliga** o bit.
- Se só os horários mudaram, `novo == antigo` e nada entra na fila → a porta não abre.

4. **Grava tudo** e devolve o navegador para a página:

```cpp
  salvarCadastro();

  server.sendHeader("Location", "/");
  server.send(303);
```

A abertura das portas **não** acontece aqui: quem cuida disso é o `loop()` (Passo 10),
um compartimento de cada vez.

## Passo 9 — Movendo as portas (servos)

**O que faz:** abre e fecha as portas **devagar e sem trancos**. Cada movimento dura
7 s: a porta começa lenta, acelera no meio e freia ao chegar.

```cpp
// Duracao de cada movimento de porta (abrir ou fechar), em milissegundos.
// Aumente para deixar as portas mais lentas.
const unsigned long TEMPO_MOVIMENTO_PORTA = 7000;

// Largura do pulso do servo em 0 e em 180 graus (padrao do SG90/MG90).
const int PULSO_0_GRAU = 544;
const int PULSO_180_GRAUS = 2400;

// Resolucao do sinal dos servos: 16 bits dao cerca de 0,3 us por unidade (o
// padrao, 10 bits, so tem cerca de 20 us, quase 2 graus).
const int RESOLUCAO_SERVO = 16;

int pulsoDoAngulo(float angulo) {
  return PULSO_0_GRAU + (int)round(angulo * (PULSO_180_GRAUS - PULSO_0_GRAU) / 180.0);
}

// Move a porta devagar e sem trancos: comeca lento, acelera no meio e freia no
// fim (curva de cosseno). Um passo a cada 20 ms, o intervalo do sinal do servo.
// Exige os servos em 5 V: com tensao baixa eles nao tem forca para os avancos
// pequenos, param zumbindo e depois saltam.
void moverPorta(int c, int de, int para) {
  const int passos = TEMPO_MOVIMENTO_PORTA / 20;
  for (int i = 1; i <= passos; i++) {
    float t = (float)i / passos;          // 0 -> 1 ao longo do movimento
    float suave = (1 - cos(t * PI)) / 2;  // 0 -> 1, lento no inicio e no fim
    servos[c].writeMicroseconds(pulsoDoAngulo(de + (para - de) * suave));
    delay(20);
  }
}
```

- **Passos:** 7.000 ms ÷ 20 ms = **350 posições** por movimento. O servo recebe uma
  nova posição a cada pulso do seu sinal (a cada 20 ms).
- **Curva suave:** `(1 − cos(t·π)) / 2` vai de 0 a 1 com início e fim lentos. Na
  abertura, a porta está em ~4° após 1 s, em 45° na metade do tempo e chega a 90°
  aos 7 s. A velocidade máxima, no meio do curso, fica em cerca de 20° por segundo.
  Isso evita o impacto da tampa no fim do curso e reduz o pico de corrente na partida
  do motor.
- **Resolução do sinal:** o servo entende a posição pela largura do pulso, de 544 µs
  (0°) a 2.400 µs (180°), cerca de 10 µs por grau. Com 16 bits (`RESOLUCAO_SERVO`),
  o ESP32 ajusta o pulso em frações de microssegundo, e os avanços pequenos do início
  e do fim chegam ao servo sem arredondamento. A resolução precisa ser definida antes
  do `attach` (Passo 3).
- **Alimentação:** o movimento lento depende dos servos em **5 V**, com corrente
  suficiente (A2). Com tensão baixa, o motor não tem força para os avanços pequenos:
  para zumbindo e depois salta de uma vez.
- **Ajuste:** para mudar a velocidade, basta alterar `TEMPO_MOVIMENTO_PORTA`
  (ex.: 9000 para 9 s, mais lento; 5000 para 5 s, mais rápido).

```cpp
void abrirCompartimento(int c) {
  moverPorta(c, ANGULO_FECHADO[c], ANGULO_ABERTO[c]);
}

void fecharCompartimento(int c) {
  moverPorta(c, ANGULO_ABERTO[c], ANGULO_FECHADO[c]);
}
```

Para abrir **vários** compartimentos com um único toque, sem que dois servos se
movam juntos (o que sobrecarregaria a fonte), eles abrem **um depois do outro**:

```cpp
// Abre os compartimentos marcados, um logo apos o outro.
void abrirCompartimentos(uint8_t mascara) {
  for (int c = 0; c < NUM_COMPARTIMENTOS; c++) {
    if (temBit(mascara, c)) abrirCompartimento(c);
  }
}
```

Como `abrirCompartimento()` só termina depois que a porta chegou em 90°, o próximo
servo só começa quando o anterior parou.

## Passo 10 — O coração: `loop()` e a máquina de estados

**O que faz:** a cada volta, atende a página web, confere os horários e executa o
que o **estado atual** manda.

```cpp
void loop() {
  if (modoConfig) {
    dnsServer.processNextRequest();
  }
  server.handleClient();

  if (modoConfig) {
    return;
  }

  manterWiFi();
  gravarHoraNoRTC();
  verificarHorarios();

  switch (estadoAtual) {
```

- `manterWiFi()` e `gravarHoraNoRTC()` cuidam do relógio e da reconexão (Passo 19).
  As duas voltam na hora quando não há nada a fazer, então não atrasam o alarme.

**Mapa dos estados:**

```text
                    horário chegou
   ┌────────────┐ ───────────────────► ┌──────────┐
   │ AGUARDANDO │                      │ TOCANDO  │
   │  (relógio) │ ◄─── 12 min sem ──── │ (alarme) │
   └────────────┘      acesso          └──────────┘
     │   ▲   ▲    (dose pendente)            │ botão
     │   │   │                               ▼
     │   │   │  fechou              ┌──────────────────────┐
     │   │   └───────────────────── │ PORTA_ABERTA_ESTADO  │
     │   │                          │ (paciente retirando) │
     │   │ fechou                   └──────────────────────┘
     ▼   │
   ┌─────────────┐
   │ ABASTECENDO │  remédio novo, reposição ou esvaziar
   └─────────────┘
```

No estado **AGUARDANDO**, a ordem de prioridade é:

```cpp
    case AGUARDANDO:
      if (dosePendente && digitalRead(BUTTON_PIN) == LOW) {
        abrirParaPaciente();
        break;
      }
      // Prioridade: alarme em espera; depois abastecimento de compartimento novo.
      if (mascaraEmEspera != 0) {
        uint8_t mascara = mascaraEmEspera;
        mascaraEmEspera = 0;
        iniciarAlarme(mascara, horarioEmEspera);
        break;
      }
      if (filaAbastecimento != 0) {
```

1. Dose pendente + botão → abre para o paciente.
2. Algum horário esperando → começa o alarme.
3. Algum compartimento novo na fila → abre para abastecer.
4. Nada disso → mostra o relógio.

## Passo 11 — Conferindo os horários

**O que faz:** uma vez por segundo, compara a hora atual com os horários de cada
remédio. Funciona **em qualquer estado**.

```cpp
  for (int c = 0; c < NUM_COMPARTIMENTOS; c++) {
    if (!medicamentoAtivo(c)) continue;
    Medicamento& m = medicamentos[c];
    for (int i = 0; i < m.totalHorarios; i++) {
      if (m.jaDisparado[i] || timeinfo.tm_hour != m.hora[i] || timeinfo.tm_min != m.minuto[i]) continue;
      m.jaDisparado[i] = true;
      if (mascaraEmEspera == 0) horarioEmEspera = formatarHorario(m.hora[i], m.minuto[i]);
      mascaraEmEspera |= (uint8_t)(1 << c);
    }
  }
```

- Quando bate o horário, o compartimento entra na **máscara de espera**.
- **Dois remédios no mesmo horário** entram na mesma máscara → viram **um único
  alarme**.
- Se o dispenser estiver ocupado (ex.: cuidador repondo outro compartimento), o
  horário **fica esperando** e toca assim que ele voltar a `AGUARDANDO`.
- `jaDisparado` impede de tocar de novo no mesmo minuto; ele é "rearmado" quando o
  minuto muda:

```cpp
        if (timeinfo.tm_min != medicamentos[c].minuto[i]) medicamentos[c].jaDisparado[i] = false;
```

## Passo 12 — O alarme tocando

**O que faz:** `iniciarAlarme()` prepara a dose e muda para `TOCANDO`.

```cpp
void iniciarAlarme(uint8_t mascara, const String& horario) {
  estadoAtual = TOCANDO;
  doseMascara = mascara;
  horarioDose = horario;
  nomesDose = juntarNomes(mascara);
  alarmeIniciadoEm = millis();
  nivelAvisoEnviado = 0;
  dosePendente = false;
```

- `nomesDose` guarda o texto "Losartana e Metformina" para as mensagens.
- `alarmeIniciadoEm` marca o instante do início: todos os tempos são contados a
  partir dele.

**Ciclo do som** — 1 minuto tocando, 1 minuto em silêncio:

```cpp
      bool minutoDeSom = ((decorrido / CICLO_ALARME) % 2) == 0;
      if (!minutoDeSom) {
        if (ledBuzzerLigado) desligarLedBuzzer();
        break;
      }

      if (millis() - ultimoToggleAlarme >= 150) {
        ultimoToggleAlarme = millis();
        ledBuzzerLigado = !ledBuzzerLigado;
        digitalWrite(LED_PIN, ledBuzzerLigado ? HIGH : LOW);
        digitalWrite(BUZZER_PIN, ledBuzzerLigado ? HIGH : LOW);
      }
```

- `decorrido / CICLO_ALARME` = quantos minutos se passaram (0, 1, 2, …).
- `% 2 == 0` → minutos pares (0, 2, 4…) tocam; ímpares ficam em silêncio.
- Dentro do minuto de som, LED e buzzer **invertem a cada 150 ms** (bip-bip-bip).

**Avisos** — aos 6 minutos para o cuidador, aos 12 para todos:

```cpp
      if (decorrido >= TEMPO_PRIMEIRO_AVISO && nivelAvisoEnviado == 0) {
        desligarLedBuzzer();
        escreverLinhaLCD(1, "Avisando cuidad.");
        avisarPrimeiroAtraso();
        nivelAvisoEnviado = 1;
      }
```

```cpp
      if (decorrido >= TEMPO_ALERTA_FINAL) {
        desligarLedBuzzer();
        lcd.clear();
        escreverLinhaLCD(0, "Avisando familia");
        atualizarDose(DOSE_SEM_ACESSO, decorrido);
        alertarSemAcesso();
        nivelAvisoEnviado = 2;
```

```cpp
        dosePendente = true;
        lcd.clear();
        estadoAtual = AGUARDANDO;
```

- `nivelAvisoEnviado` evita mandar o mesmo aviso duas vezes.
- Depois dos 12 minutos o alarme **para**, mas a dose fica **pendente**: se o
  paciente aparecer mais tarde, o botão ainda abre os compartimentos.

## Passo 13 — O paciente aperta o botão

**O que faz:** registra o acesso, desliga o alarme e **abre todos os
compartimentos da dose**, um após o outro.

```cpp
void abrirParaPaciente() {
  unsigned long decorrido = millis() - alarmeIniciadoEm;
  atualizarDose(decorrido < TEMPO_PRIMEIRO_AVISO ? DOSE_NO_HORARIO : DOSE_ATRASADA, decorrido);
  esquecerRegistrosDose();

  desligarLedBuzzer();
  dosePendente = false;

  lcd.clear();
  escreverLinhaLCD(0, "Retire: " + listaCompartimentos(doseMascara));
  escreverLinhaLCD(1, "Abrindo...");
  abrirCompartimentos(doseMascara);

  mascaraAberta = doseMascara;
  estadoAtual = PORTA_ABERTA_ESTADO;
  portaAbertaEm = millis();

  avisarAcessoAposAviso();
}
```

- Antes do 1º aviso → "tomada no horário"; depois → "tomada com atraso" (Passo 16).
- Se já tinha avisado alguém, `avisarAcessoAposAviso()` manda "Paulo acessou o
  dispenser às 15:27", para a família ficar tranquila.

**Fechando — trava de 7 segundos:** logo depois de abrir, o dedo do paciente
ainda pode estar no botão. Para não fechar sem querer, o botão só vale depois de 7 s.
Se ninguém apertar, fecha sozinho após 3 minutos:

```cpp
      bool travaLiberada = (millis() - portaAbertaEm >= TRAVA_BOTAO);
      bool fechar = (travaLiberada && digitalRead(BUTTON_PIN) == LOW) ||
                    (millis() - portaAbertaEm >= TEMPO_PORTA_ABERTA);

      if (fechar) {
        lcd.clear();
        escreverLinhaLCD(0, "Fechando porta..");
        fecharCompartimentos(mascaraAberta);
        mascaraAberta = 0;
```

## Passo 14 — Abastecer, repor e esvaziar

Os três casos usam a **mesma função**, que abre **um** compartimento para o cuidador
e só muda o texto do LCD:

```cpp
void iniciarAbastecimento(int c, ModoAbastecimento modo) {
  compartimentoAbastecendo = c;
  modoAbastecimento = modo;

  String titulo;
  if (modo == ABAST_REPOR) titulo = "Repor compart." + String(c + 1);
  else if (modo == ABAST_ESVAZIAR) titulo = "Esvaziar comp." + String(c + 1);
  else titulo = "Abast. compart." + String(c + 1);
```

**a) Abastecimento guiado (remédio novo):** o `loop()` pega o **primeiro**
compartimento da fila, tira ele da fila e abre. Quando a porta fecha, o estado volta
para `AGUARDANDO` e o próximo da fila abre — um de cada vez:

```cpp
        for (int c = 0; c < NUM_COMPARTIMENTOS; c++) {
          if (!temBit(filaAbastecimento, c)) continue;
          filaAbastecimento &= (uint8_t)~(1 << c);
          iniciarAbastecimento(c, ABAST_NOVO);
          break;
        }
```

**b) Reposição:** na página, o cuidador **escolhe o remédio** (os botões de opção só
mostram os cadastrados), confirma, e o navegador envia o número do compartimento:

```cpp
  html += "  var corpo = new URLSearchParams(); corpo.append('c', reporEscolhido);";
  html += "  fetch('/abrir-manual', {method:'POST', body: corpo}).then(function(r){";
```

A placa confere se o pedido é válido e se está livre, e abre **só aquele**:

```cpp
void handleAbrirManual() {
  int c = server.arg("c").toInt();
  if (!server.hasArg("c") || c < 0 || c >= NUM_COMPARTIMENTOS || !medicamentoAtivo(c)) {
    server.send(400, "text/plain", "Compartimento invalido");
    return;
  }
  if (!dispenserLivre()) {
    server.send(409, "text/plain", "Sistema ocupado no momento");
    return;
  }

  server.send(200, "text/plain", "OK");
  iniciarAbastecimento(c, ABAST_REPOR);
}
```

**c) Esvaziar:** apaga o remédio do compartimento e, se o cuidador pediu, abre para
retirar as sobras:

```cpp
  medicamentos[c].nome = "";
  medicamentos[c].totalHorarios = 0;
  filaAbastecimento &= (uint8_t)~(1 << c);
  salvarMedicamento(c);
```

## Passo 15 — Avisos pelo Telegram

**Por que Telegram?** É gratuito, oficial e funciona com uma simples requisição pela
internet. (O WhatsApp gratuito via CallMeBot ficou sem vagas; o WhatsApp oficial é
pago e exige aprovação da Meta.)

**Configuração (uma vez):** o cuidador cria um bot no **BotFather**, cola o **token**
na página; cada pessoa abre o bot e toca em **Iniciar**; o botão "Buscar IDs" mostra
o `chatId` de cada uma.

**Enviar uma mensagem** é fazer um pedido HTTPS para a API do Telegram:

```cpp
  String url = "https://api.telegram.org/bot" + token + "/" + metodo;
  if (!http.begin(cliente, url)) {
    Serial.println("Telegram: falha ao iniciar conexao");
    return -1;
  }
  http.addHeader("Content-Type", "application/x-www-form-urlencoded");
  int codigo = http.POST(corpo);
```

```cpp
  String corpo = "chat_id=" + codificarURL(contato.chatId) + "&text=" + codificarURL(texto);
  int codigo = chamarTelegram(tokenTelegram, "sendMessage", corpo);
```

- `codificarURL()` troca espaços e acentos por códigos (`%20`, `%C3%A3`…), porque o
  endereço/corpo do pedido só aceita alguns caracteres.
- A resposta `200` significa "entregue ao Telegram".

**As mensagens:**

```cpp
void avisarPrimeiroAtraso() {
  enviarParaCuidador("Zelo+: Paciente “" + nomePaciente + "” não acessou o medicamento das “" +
                     horarioDose + "” horas (" + nomesDose + ").");
}

void alertarSemAcesso() {
  enviarParaTodos("Zelo+: Paciente “" + nomePaciente + "” não foi até o dispenser no horário das “" +
                  horarioDose + "” (" + nomesDose + ").");
}
```

| Momento | Quem recebe | Exemplo |
|---|---|---|
| 6 min sem acesso | Cuidador | Zelo+: Paciente "Paulo" não acessou o medicamento das "15:26" horas (Losartana). |
| 12 min sem acesso | Cuidador + familiares | Zelo+: Paciente "Paulo" não foi até o dispenser no horário das "15:26" (Losartana e Metformina). |
| Acesso depois de um aviso | Quem foi avisado | Zelo+: Paulo acessou o dispenser às 15:27 (dose de Losartana das 15:26). |

**Buscar IDs:** a função `handleTelegramIds()` pede ao Telegram as últimas mensagens
recebidas pelo bot (`getUpdates`) e usa a **ArduinoJson** para ler só o que
interessa (id e nome de cada pessoa):

```cpp
  JsonDocument filtro;
  JsonObject chatFiltro = filtro["result"][0]["message"]["chat"].to<JsonObject>();
  chatFiltro["id"] = true;
  chatFiltro["first_name"] = true;
  chatFiltro["last_name"] = true;
  chatFiltro["username"] = true;
```

O **filtro** economiza memória: a resposta do Telegram tem muitos campos, mas a placa
guarda apenas esses quatro.

## Passo 16 — Histórico de doses

**O que faz:** cada remédio de cada alarme vira um **registro** com data, situação e
atraso. Serve para calcular a **adesão ao tratamento**.

```cpp
struct RegistroDose {
  uint32_t inicio;         // horario do disparo (segundos desde 1970)
  uint16_t atrasoSeg;      // tempo ate o acesso
  uint8_t status;
  uint8_t compartimento;   // 0..2
  char remedio[20];        // nome do medicamento no momento da dose
};
```

```cpp
enum StatusDose : uint8_t {
  DOSE_PENDENTE = 0,    // alarme tocando (ou placa reiniciou antes de concluir)
  DOSE_NO_HORARIO = 1,  // acesso antes do primeiro aviso ao cuidador
  DOSE_ATRASADA = 2,    // acesso depois do primeiro aviso (inclusive apos o alerta final)
  DOSE_SEM_ACESSO = 3   // alerta final enviado e ninguem acessou
};
```

**Buffer circular:** a placa guarda as **60 doses mais recentes**. Quando enche, a
próxima sobrescreve a mais antiga — como uma fila que dá a volta:

```cpp
int registrarInicioDose(int compartimento) {
  int idx = proximoHistorico;
```

```cpp
  proximoHistorico = (proximoHistorico + 1) % MAX_HISTORICO;
  if (totalHistorico < MAX_HISTORICO) totalHistorico++;
  return idx;
}
```

- `% MAX_HISTORICO` (resto da divisão) faz a posição voltar a 0 depois da 59.

Para ler do mais recente para o mais antigo:

```cpp
int indiceHistorico(int k) {
  return (proximoHistorico - 1 - k + 2 * MAX_HISTORICO) % MAX_HISTORICO;
}
```

**Adesão** = doses tomadas (no horário + com atraso) ÷ doses concluídas, nos últimos
7 dias. O arredondamento é feito somando metade do divisor:

```cpp
int percentual(int parte, int total) {
  return (parte * 100 + total / 2) / total;
}
```

A página mostra a adesão geral e por remédio, a tabela das 20 doses mais recentes e
o link **Baixar histórico (CSV)**, que abre no Excel/Google Planilhas:

```cpp
  String csv = "data;horario;medicamento;compartimento;situacao;atraso_minutos\r\n";
```

## Passo 17 — Escrevendo no LCD

**O problema:** o LCD 16x2 não tem letras acentuadas. "Medicação" apareceria com
símbolos estranhos. **A solução:** duas técnicas combinadas.

**1. Caracteres especiais desenhados no LCD.** O LCD permite criar até 8 caracteres
próprios, cada um desenhado numa grade de 5 × 8 pontos (cada linha da grade é um número
binário: `1` = ponto aceso). O Zelo+ cria o **ç** e o **ã**, que aparecem na tela de
espera:

```cpp
const uint8_t LCD_CEDILHA = 1;
const uint8_t LCD_A_TIL = 2;
uint8_t DESENHO_CEDILHA[8] = {0b00000, 0b01110, 0b10000, 0b10000, 0b10001, 0b01110, 0b00100, 0b01100};
uint8_t DESENHO_A_TIL[8] = {0b01101, 0b10010, 0b01110, 0b00001, 0b01111, 0b10001, 0b01111, 0b00000};
```

```text
  ç (código 1)      ã (código 2)
  · · · · ·         · █ █ · █
  · █ █ █ ·         █ · · █ ·
  █ · · · ·         · █ █ █ ·
  █ · · · ·         · · · · █
  █ · · · █         · █ █ █ █
  · █ █ █ ·         █ · · · █
  · · █ · ·         · █ █ █ █
  · █ █ · ·         · · · · ·
```

Os desenhos são gravados no LCD uma vez, ao ligar (no `setup()`):

```cpp
  lcd.createChar(LCD_CEDILHA, DESENHO_CEDILHA);
  lcd.createChar(LCD_A_TIL, DESENHO_A_TIL);
```

**2. As outras letras acentuadas perdem o acento.** Em UTF-8 (o formato do texto), as
letras acentuadas usam **2 bytes**, e o primeiro é sempre `0xC3`. O segundo byte diz
qual é a letra. O "ç" (`0xA7`) e o "ã" (`0xA3`) viram os caracteres especiais; as
outras viram a letra sem acento:

```cpp
    if (c == 0xC3 && i + 1 < texto.length()) {
      uint8_t original = (uint8_t)texto[++i];
      if (!maiusculas && original == 0xA7) { saida += (char)LCD_CEDILHA; continue; }
      if (!maiusculas && original == 0xA3) { saida += (char)LCD_A_TIL; continue; }
      uint8_t d = original | 0x20; // 0x80-0x9F (maiusculas) -> minusculas
      char base = '?';
      if (d >= 0xA0 && d <= 0xA5) base = 'A';
      else if (d == 0xA7) base = 'C';
      else if (d >= 0xA8 && d <= 0xAB) base = 'E';
```

Os **nomes dos remédios** são mostrados em **maiúsculas** (parâmetro `maiusculas`), o que
facilita a leitura: `"Losartana Potássica"` → `"LOSARTANA POTASS"` (cortado em 16
colunas).

E uma função que **sempre preenche a linha inteira**, apagando restos de textos
anteriores:

```cpp
void escreverLinhaLCD(int linha, const String& texto) {
  String t = textoLCD(texto);
  while (t.length() < 16) t += ' ';
  lcd.setCursor(0, linha);
  lcd.print(t);
}
```

Na **tela de espera**, a linha 1 mostra a hora centralizada e a linha 2, a situação das
doses:

```cpp
  // Linha 1: hora e minuto, centralizados.
  char horaBuffer[6];
  strftime(horaBuffer, sizeof(horaBuffer), "%H:%M", &timeinfo);
  escreverLinhaLCD(0, String("     ") + horaBuffer);

  int ativos = totalMedicamentosAtivos();
  if (dosePendente) {
    escreverLinhaLCD(1, "Dose pendente!");
  } else if (ativos > 0) {
    escreverLinhaLCD(1, "Medicação em dia");
  } else {
    escreverLinhaLCD(1, "Sem remédio");
  }
```

| Situação | Linha 1 | Linha 2 |
|---|---|---|
| Aguardando | `10:30` (centralizado) | `Medicação em dia` |
| Alarme | `Hora do remedio!` | `LOSARTANA (C1)` (alterna a cada 2 s) |
| Retirada | `Retire: C1 C2` | `Fecha em: 170s` |
| Abastecer / Repor | `Abast. compart.2` / `Repor compart.2` | `METFORMINA` |
| Dose pendente | `15:40` (centralizado) | `Dose pendente!` |
| Nenhum remédio cadastrado | hora (centralizada) | `Sem remedio` |
| Hora desconhecida (sem internet e sem DS3231) | `Acerte a hora` | `pelo celular` (LED piscando) |
| Rede própria ao ligar (Passo 4) | `Rede ZeloPlus` / `Pagina:` | `senha zelo1234` / `192.168.4.1` |

Quando a hora não é conhecida, os alarmes não podem disparar. Para que a situação não
passe despercebida, a tela de espera pede o acerto e o LED pisca:

```cpp
  if (!getLocalTime(&timeinfo, 10)) {
    avisoHoraAtivo = true;
    escreverLinhaLCD(0, "Acerte a hora");
    escreverLinhaLCD(1, "pelo celular");
    digitalWrite(LED_PIN, digitalRead(LED_PIN) == HIGH ? LOW : HIGH);
    return;
  }
```

## Passo 18 — Modo de teste

Esperar 12 minutos a cada teste seria lento. Uma única linha troca todos os tempos:

```cpp
#define MODO_TESTE 1

#if MODO_TESTE
const unsigned long CICLO_ALARME = 5UL * 1000UL;
const unsigned long TEMPO_PRIMEIRO_AVISO = 30UL * 1000UL;
const unsigned long TEMPO_ALERTA_FINAL = 60UL * 1000UL;
#else
const unsigned long CICLO_ALARME = 60UL * 1000UL;
const unsigned long TEMPO_PRIMEIRO_AVISO = 6UL * 60UL * 1000UL;
const unsigned long TEMPO_ALERTA_FINAL = 12UL * 60UL * 1000UL;
#endif
```

- `#if` é resolvido **na compilação**: só um dos blocos vai para a placa.
- Com `MODO_TESTE 1`: aviso aos 30 s, alerta aos 60 s, som 5 s / silêncio 5 s.
- **Antes do uso real**, trocar para `#define MODO_TESTE 0` e gravar de novo.
- O `UL` ("unsigned long") evita que a conta estoure: `12 * 60 * 1000` passa do
  limite de um `int` em algumas placas.

## Passo 19 — Relógio DS3231 (próxima etapa)

**O que faz:** se o **módulo de relógio DS3231** estiver ligado, o dispenser sabe a
hora **mesmo sem internet**. Sem o módulo, nada muda: a hora continua vindo da
internet (Passo 5). O **mesmo programa** serve para os dois casos, então o módulo pode
ser ligado depois, sem gravar o programa de novo.

**Por que existe:** o relógio interno do ESP32 **zera quando a placa desliga**. Ao
religar, ele só volta a saber a hora quando a internet responde. Se a energia voltar
com o roteador ainda desligado, os alarmes não tocariam. O DS3231 tem **bateria
própria** (LIR2032) e continua contando o tempo com o dispenser desligado.

**Ligação:** no barramento I2C do ESP32 — SDA → GPIO 21, SCL → GPIO 22, VCC → 3V3,
GND → GND (diagrama na [E3](#e3-a-solução-fonte-5-v3-a--módulo-ups--bateria-18650);
detalhes do módulo na [E9](#e9-módulo-de-relógio-ds3231)). O relógio, no endereço `0x68`,
é a única peça nesses fios: a tela usa o SPI, em outros pinos.

**1. As variáveis do relógio**

```cpp
// ---------- RELOGIO DS3231 (opcional) ----------
// Modulo de relogio ligado no I2C, junto com o LCD (endereco 0x68). Guarda a hora
// certa mesmo sem internet e sem energia. Sem o modulo, tudo funciona como antes,
// com a hora vinda da internet (NTP).
RTC_DS3231 rtc;
bool rtcPresente = false;             // o modulo respondeu no I2C ao ligar
bool horaDoRtc = false;               // a hora atual veio do DS3231 ao ligar
volatile bool ntpSincronizou = false; // avisado pelo NTP a cada acerto de hora
const uint32_t HORA_MINIMA_VALIDA = 1704067200UL; // 01/01/2024: antes disso, hora invalida
```

- `rtc` é o objeto que conversa com o módulo (biblioteca `RTClib`, da Adafruit).
- `HORA_MINIMA_VALIDA` é 1º de janeiro de 2024, contado em **segundos desde 1970**
  (o jeito que computadores guardam datas). Uma hora anterior a isso só pode estar
  errada — por exemplo, um módulo novo que nunca foi acertado.
- `volatile` avisa o compilador de que a variável pode mudar "por fora" do `loop()`:
  quem a muda é o NTP, que roda em paralelo.

**2. Ao ligar: procurar o módulo e usar a hora dele**

```cpp
void iniciarRelogioRTC() {
  rtcPresente = rtc.begin();
  if (!rtcPresente) {
    Serial.println("DS3231 nao encontrado - usando so a internet");
    return;
  }
  if (rtc.lostPower()) {
    Serial.println("DS3231 sem hora valida - aguardando a internet");
    return;
  }
  uint32_t segundos = rtc.now().unixtime();
  if (segundos < HORA_MINIMA_VALIDA) {
    Serial.println("DS3231 com data antiga - aguardando a internet");
    return;
  }
  struct timeval agora = { (time_t)segundos, 0 };
  settimeofday(&agora, nullptr);
  horaDoRtc = true;
  Serial.println("DS3231: hora carregada do relogio");
}
```

- `rtc.begin()` "chama" o endereço `0x68`. **Sem o módulo, ninguém responde** e a
  função devolve `false` em uma fração de segundo: o programa anota e segue.
- `rtc.lostPower()` avisa se o módulo **perdeu a hora** (nunca foi acertado ou ficou
  sem bateria). Nesse caso o programa não confia nele e espera a internet.
- `settimeofday()` acerta o **relógio interno do ESP32** com a hora do módulo. Daí em
  diante, `getLocalTime()` (usado no relógio do LCD e na conferência dos horários)
  funciona normalmente, com ou sem internet.

**3. Com internet: manter o módulo sempre certo**

```cpp
// Chamada pelo NTP (fora do loop) sempre que a hora e acertada pela internet.
void aoSincronizarNTP(struct timeval* tv) {
  ntpSincronizou = true;
}
```

```cpp
void gravarHoraNoRTC() {
  if (!ntpSincronizou) return;
  ntpSincronizou = false;
  if (!rtcPresente) return;
  time_t agora = time(nullptr);
  if ((uint32_t)agora < HORA_MINIMA_VALIDA) return;
  rtc.adjust(DateTime((uint32_t)agora));
  Serial.println("DS3231: hora gravada (vinda da internet)");
}
```

- O NTP acerta a hora ao conectar e depois **a cada hora**, mais ou menos. A cada
  acerto, `aoSincronizarNTP` só levanta uma "bandeira".
- Quem grava no módulo é `gravarHoraNoRTC()`, chamada pelo `loop()` (Passo 10). Assim a
  gravação nunca acontece no meio de uma escrita no LCD, que usa os mesmos fios.
- `rtc.adjust()` grava a hora e **apaga o aviso de hora perdida**: no próximo
  religamento, `lostPower()` já responde que a hora é confiável.
- O módulo guarda a hora **mundial (UTC)**; o fuso de Brasília é aplicado pelo
  `configTime()` na hora de mostrar. Por isso a hora não "anda" 3 horas ao religar.

**4. Sem internet: continuar tentando o Wi-Fi**

```cpp
void manterWiFi() {
  static unsigned long ultimaTentativa = 0;
  static bool estavaConectado = true;
  if (modoLocal) {
    manterRedeLocal();
    return;
  }
  bool conectado = (WiFi.status() == WL_CONNECTED);
  if (conectado && !estavaConectado) {
    Serial.print("Wi-Fi reconectado. Acesse: http://");
    Serial.println(WiFi.localIP());
  }
  estavaConectado = conectado;
  if (conectado || millis() - ultimaTentativa < 30000) return;
  ultimaTentativa = millis();
  WiFi.reconnect();
}
```

- Se a conexão **cair com o dispenser em funcionamento**, tenta a rede salva **a cada
  30 s**, sem travar o programa (o alarme continua funcionando enquanto isso).
- Se o dispenser **ligou sem a rede salva**, ele está na rede própria e as tentativas
  são feitas a cada 10 minutos por `manterRedeLocal()` (Passo 4).
- Quando conecta, a página volta a abrir **no mesmo IP**, o Telegram volta a funcionar e
  o NTP acerta a hora (e o DS3231 é regravado).

**5. Na página: o relógio foi encontrado?**

No rodapé, abaixo de "Trocar rede Wi-Fi", aparece o estado do módulo:

```cpp
  html += "<p class='rodape' style='font-size:15px;color:#6b7280;margin-top:0'>&#128339; Relógio DS3231: ";
  html += rtcPresente ? "conectado" : "não instalado (hora pela internet)";
  html += "</p>";
```

**Resumo: o que acontece ao ligar**

| Situação ao ligar | O que o programa faz |
|---|---|
| **Sem o módulo** | Segue como antes: hora pela internet. Página: "não instalado". |
| **Módulo novo** (nunca acertado) | Espera a internet; no primeiro acerto, **grava a hora no módulo**. |
| **Módulo com hora, com internet** | Usa a hora do módulo na hora; o NTP confere e regrava a cada acerto. |
| **Módulo com hora, sem internet** | Rede própria `ZeloPlus` (Passo 4) com a hora do módulo: **alarmes funcionam**; rede salva tentada a cada 10 minutos. |
| **Nenhuma rede cadastrada** | Modo de configuração (Passo 4), como antes. |

As mensagens do Serial Monitor de cada situação estão na [E9](#e9-módulo-de-relógio-ds3231).

> **Instalar o módulo depois:** desligue o dispenser da energia, ligue os 4 fios e
> religue. Não é preciso gravar o programa de novo. O módulo só é procurado **ao
> ligar**; por isso o religamento é necessário.

> A biblioteca `RTClib` está no `platformio.ini`
> (`adafruit/RTClib^2.1.4`). O PlatformIO baixa sozinho no próximo **Build**.

---

## Passo 20 — Leitura da caixa do remédio por foto (IA)

**O que faz:** no cadastro, o botão **"Foto da caixa do remédio"** abre a câmera do
celular. A foto é enviada ao dispenser, que consulta um modelo de inteligência
artificial com visão (Gemini, do Google). O modelo lê o **nome** e a
**concentração** impressos na embalagem e, se estiverem visíveis, os dígitos do
**código de barras**. O cuidador confere o resultado e só então o nome é preenchido.
É a primeira funcionalidade da [Parte H](#parte-h--evolução-do-produto-funcionalidades-com-inteligência-artificial)
(H3.1).

**Por que existe:** digitar o nome do remédio é a etapa do cadastro mais sujeita a
erro, especialmente a concentração (50 mg × 100 mg). A leitura da própria embalagem
reduz esse risco e simplifica o uso.

**Fluxo completo:**

| Etapa | Onde acontece | O que acontece |
|---|---|---|
| 1. Foto | Celular | A câmera abre pelo campo de arquivo da página, que funciona na página local (sem HTTPS). |
| 2. Redução | Celular | A página reduz a foto para até 900 px e ~100 KB (JPEG), pois a memória do ESP32 é limitada. |
| 3. Envio | Celular → ESP32 | A foto chega em pedaços (`receberFoto`) e é guardada numa única área de memória. |
| 4. Consulta | ESP32 → IA | O ESP32 monta o pedido e envia a foto em base64, convertida durante o envio. |
| 5. Resposta | IA → ESP32 → Celular | O modelo devolve um JSON com nome, concentração e código; o ESP32 repassa à página. |
| 6. Confirmação | Celular | A página mostra o que foi lido; o nome só é preenchido se o cuidador confirmar. |

**1. O botão na página (reduzindo a foto no celular)**

```cpp
  html += "<button type='button' class='secundario' onclick='tirarFoto(" + String(c) + ")'>&#128247; Foto da caixa do remédio</button>";
  html += "<input type='file' accept='image/*' capture='environment' id='foto-" + String(c) + "' style='display:none' onchange='enviarFoto(" + String(c) + ", this)'>";
```

```cpp
  html += "function comprimirFoto(img, lado, qualidade, pronto) {";
  html += "  var escala = Math.min(1, lado / Math.max(img.width, img.height));";
  ...
  html += "  tela.toBlob(function(foto) {";
  html += "    if (foto.size > 100000 && lado > 500) { comprimirFoto(img, Math.round(lado * 0.8), 0.6, pronto); return; }";
  html += "    pronto(foto);";
  html += "  }, 'image/jpeg', qualidade);";
```

- `capture='environment'`: abre direto a câmera traseira do celular.
- `comprimirFoto`: redesenha a foto menor num `canvas`; se ainda passar de 100 KB,
  tenta de novo com 80 % do tamanho.

**2. Recebendo a foto no ESP32, em pedaços**

```cpp
void receberFoto() {
  HTTPUpload& envio = server.upload();
  if (envio.status == UPLOAD_FILE_START) {
    descartarFoto();
    fotoRecusada = false;
  } else if (envio.status == UPLOAD_FILE_WRITE) {
    ...
    uint8_t* maior = (uint8_t*)realloc(fotoRecebida, fotoTamanho + envio.currentSize);
    ...
    memcpy(fotoRecebida + fotoTamanho, envio.buf, envio.currentSize);
    fotoTamanho += envio.currentSize;
  }
}
```

- A foto nunca é copiada duas vezes: o ESP32 tem pouco mais de 300 KB de memória de
  trabalho, e parte dela já é usada pelo Wi-Fi e pela conexão segura.

**3. O pedido à IA**

O pedido segue a API do Gemini, método `generateContent` (GOOGLE, 2026a). A classe `CorpoPedidoIA`
envia, em sequência, o início do JSON, a foto convertida em base64 no momento do envio
e o fim do JSON, que traz as instruções e o formato da resposta:

```cpp
const char* PEDIDO_IA_INICIO =
    "{\"contents\":[{\"parts\":[{\"inline_data\":{\"mime_type\":\"image/jpeg\",\"data\":\"";
```

```cpp
  String endereco = "https://generativelanguage.googleapis.com/v1beta/models/" + modeloIA + ":generateContent";
  if (http.begin(cliente, endereco)) {
    http.addHeader("Content-Type", "application/json");
    http.addHeader("x-goog-api-key", chaveIA);
```

| Parâmetro | Função |
|---|---|
| `modeloIA` | Modelo do Gemini com visão; o padrão é `gemini-3.5-flash`, e o nome pode ser trocado na página sem gravar o programa de novo. |
| `inline_data` | A foto da embalagem, em JPEG codificado em base64. |
| `responseMimeType` e `responseSchema` | Obrigam a resposta a vir em JSON com os campos `nome`, `concentracao`, `codigo_barras` e `legivel`. |
| `x-goog-api-key` | Chave de acesso criada no Google AI Studio. |

As instruções enviadas junto com a foto pedem ao modelo que **transcreva exatamente o
que está impresso** e que **não deduza o nome a partir do código de barras**. Se o nome
não estiver legível, o campo volta vazio e `legivel` volta como falso.

**4. Conferindo a resposta**

```cpp
  if (!(leitura["legivel"] | false) || nome == "") {
    if (codigoBarras != "") {
      responderLeitura("Código de barras lido (" + codigoBarras + "), mas o nome do remédio não aparece na foto. "
                       "Fotografe a frente da caixa, onde o nome está escrito.");
    } else {
      responderLeitura("Não foi possível ler o nome do remédio. Tente uma foto mais próxima, com boa luz.");
    }
    return;
  }
```

A foto só do código de barras não basta para preencher o nome: o código identifica o
produto apenas quando consultado numa base de dados de medicamentos (lista da CMED,
[H3.1](#h3-funcionalidades-propostas)), consulta que fica para a etapa seguinte. Por
isso a leitura usa o nome impresso na embalagem.

**5. A chave da IA**

A chave de acesso do Gemini é criada gratuitamente no **Google AI Studio**
(aistudio.google.com, opção "Get API key") e cadastrada no quadro **"Leitura da caixa
por foto"**, no fim da página, do mesmo jeito que o token do Telegram (Passo 15): fica
na memória do dispenser e nunca é mostrada na página. No mesmo quadro fica o nome do
modelo usado.

| Mensagem na página | Significado |
|---|---|
| "Cadastre antes a chave da IA..." | A chave ainda não foi salva. |
| "Sem internet: a leitura por foto precisa de conexão..." | O dispenser está sem internet (por exemplo, na rede própria). |
| "Chave da IA recusada..." | Chave inválida ou revogada. |
| "Modelo de IA não encontrado..." | O nome do modelo não existe mais; conferir no Google AI Studio e corrigir no quadro. |
| "Limite de uso da IA atingido por agora..." | Limite da camada gratuita alcançado; basta tentar mais tarde. |
| "O serviço de IA está ocupado..." | Instabilidade momentânea; basta repetir. |
| "Código de barras lido (...), mas o nome do remédio não aparece na foto." | Fotografar a frente da caixa. |

**Custo de uso:** a leitura usa a **camada gratuita** da API do Gemini, que não exige
cartão de crédito e tem limites de pedidos por minuto e por dia (GOOGLE, 2026b). Como a
leitura acontece só no cadastro e na troca de remédio, algumas vezes por mês, o uso fica
muito abaixo desses limites e o custo é zero.

**Privacidade:** apenas a foto da embalagem é enviada; o nome do paciente e os horários
não saem do dispenser (princípio de [H1](#h1-princípios-de-projeto)). Nos termos da
camada gratuita, o conteúdo enviado pode ser usado pelo Google para melhorar seus
produtos (GOOGLE, 2026b). Por isso a foto deve mostrar só a embalagem, sem receitas,
nomes ou documentos. Numa versão comercial, a camada paga, cujo conteúdo não é usado
dessa forma, ou um modelo próprio (H7) evitam essa limitação.

**Ensaios da leitura por foto:**

| Ensaio | Resultado esperado |
|---|---|
| Foto da frente da caixa, com boa luz | Nome e concentração corretos; campo preenchido só após confirmar |
| Toque em "Cancelar" na confirmação | Campo permanece como estava ("Leitura descartada") |
| Foto só do código de barras | Mensagem pedindo a foto da frente da caixa, com o código lido |
| Foto desfocada ou escura | Mensagem pedindo nova foto; nenhum nome preenchido |
| Chave não cadastrada | Aviso para cadastrar a chave, sem abrir a câmera |
| Dispenser sem internet | Mensagem de falta de internet |

## Passo 21 — Modo do cuidador: abrir pelo botão, sem o celular

**O que faz:** permite ao cuidador abrir **qualquer compartimento** usando apenas o
botão do dispenser, sem a página no celular. Serve para retirar um remédio fora do
horário, repor um compartimento ou resolver uma situação de emergência com o celular
indisponível.

**Como usar:**
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

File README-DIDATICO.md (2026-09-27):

# Zelo+ — Guia didático do firmware

> Material pedagógico que explica, **passo a passo e na ordem em que as coisas
> acontecem**, como o dispenser Zelo+ funciona. Em cada etapa aparece só o
> **trecho de código** responsável por ela (o arquivo completo está em
> [`src/main.cpp`](src/main.cpp)).

<!-- so-github -->
Imagem de referência do produto Zelo+

*Imagem de referência — conceito visual do produto final (ilustrativo); não é o protótipo atual.*
<!-- /so-github -->
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

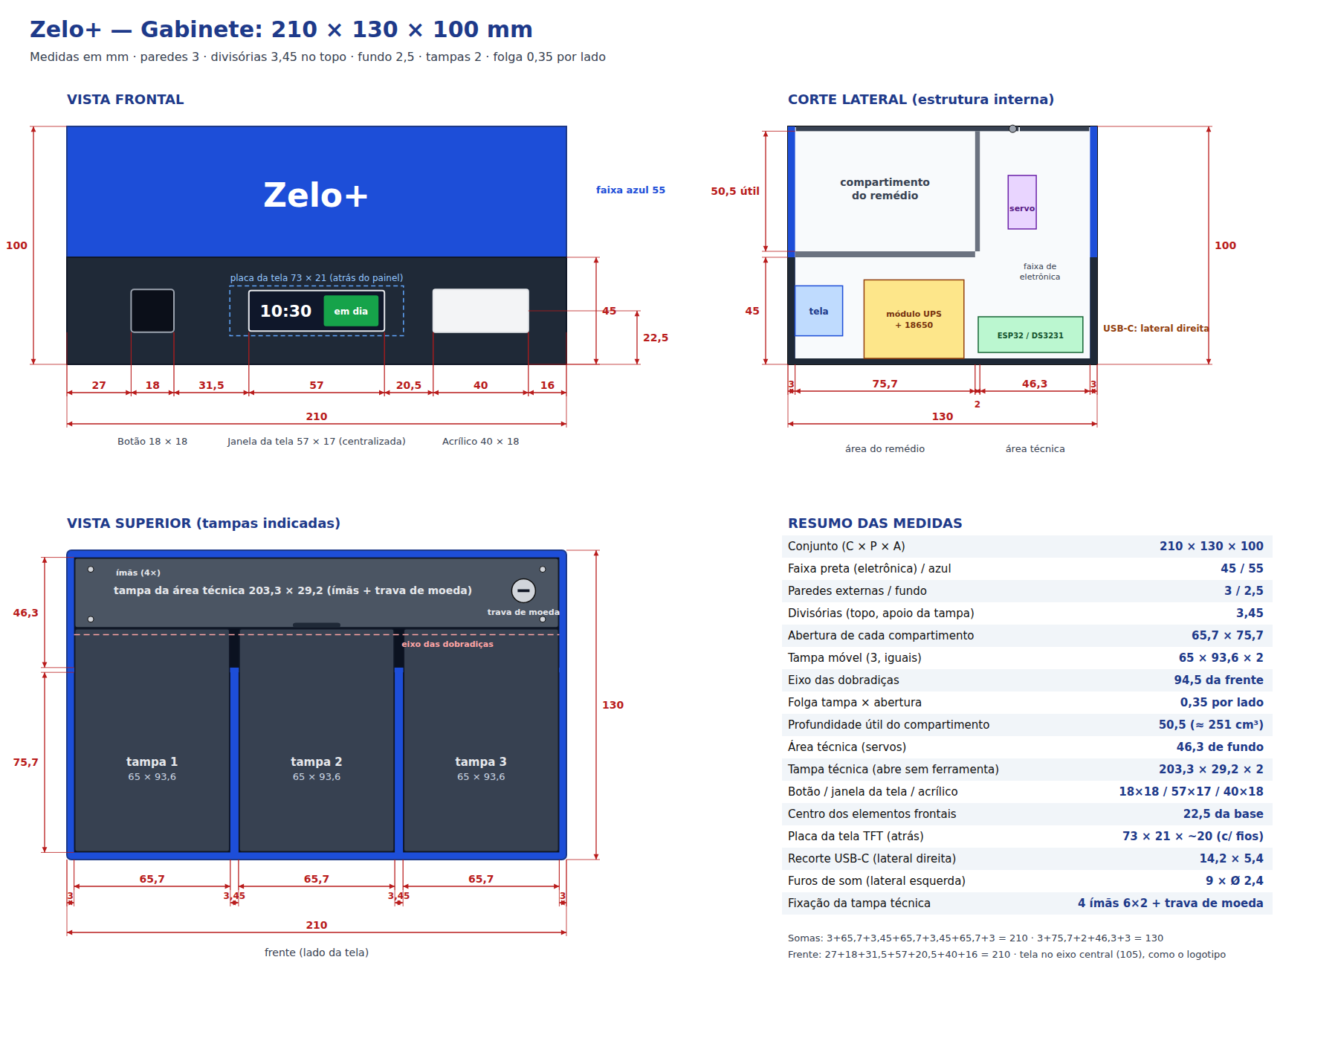
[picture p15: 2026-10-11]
docs/gabinete.png

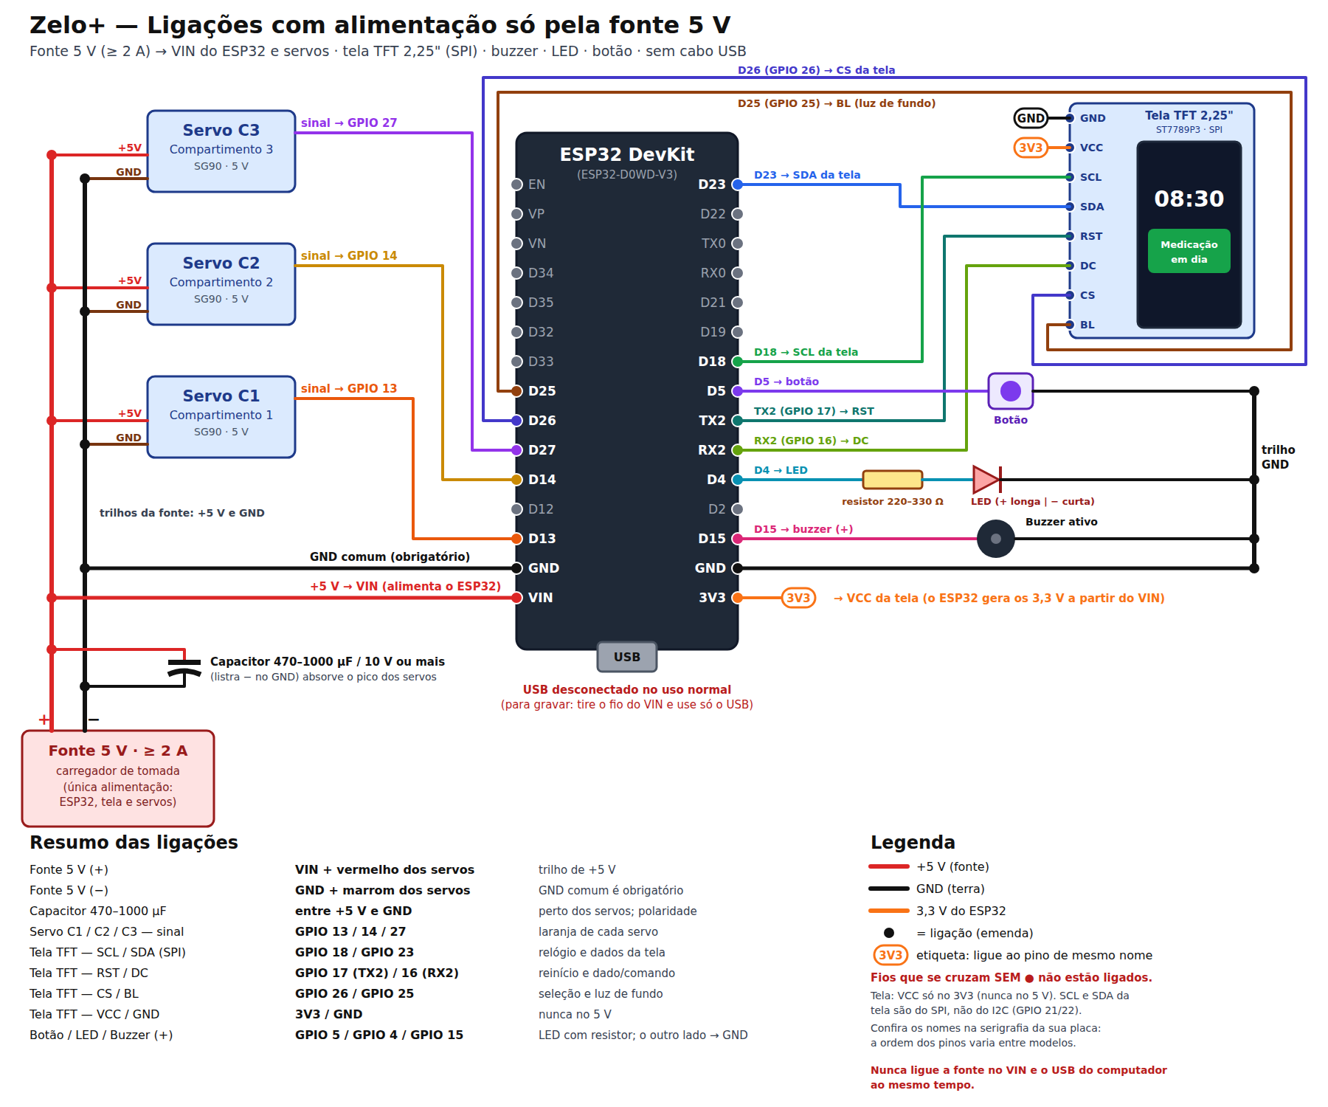
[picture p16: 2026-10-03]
docs/ligacoes-fonte5v.png

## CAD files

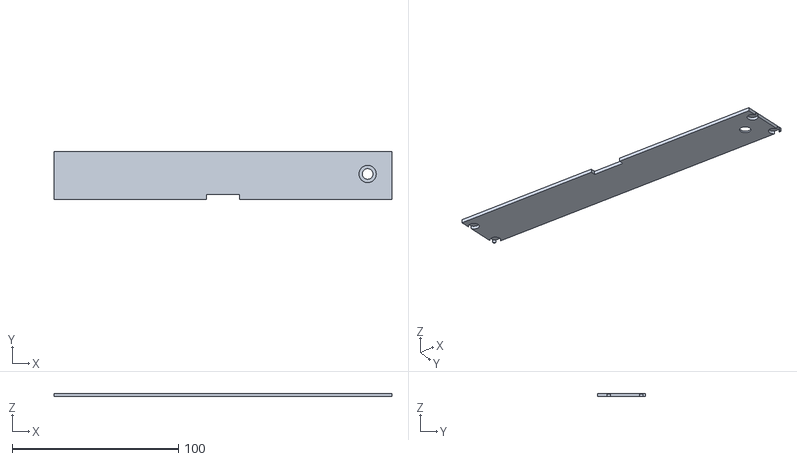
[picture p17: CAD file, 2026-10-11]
cad/gabinete/tampa-tecnica.stl
203.3 x 29.2 x 2.00

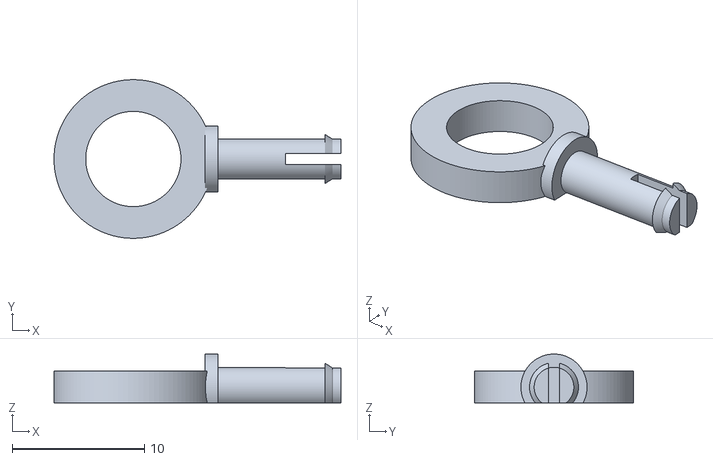
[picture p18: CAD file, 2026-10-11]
cad/pino-argola.stl
21.7 x 12.0 x 3.70

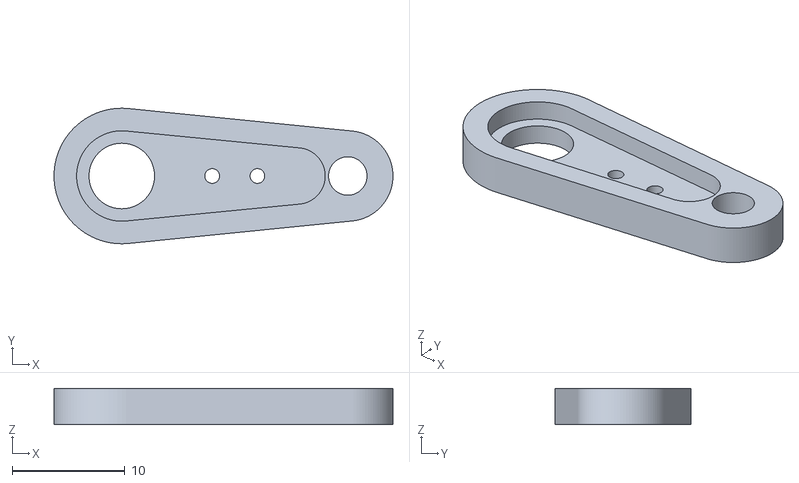
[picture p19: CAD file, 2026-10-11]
cad/braco-servo.stl
30.0 x 12.0 x 3.20

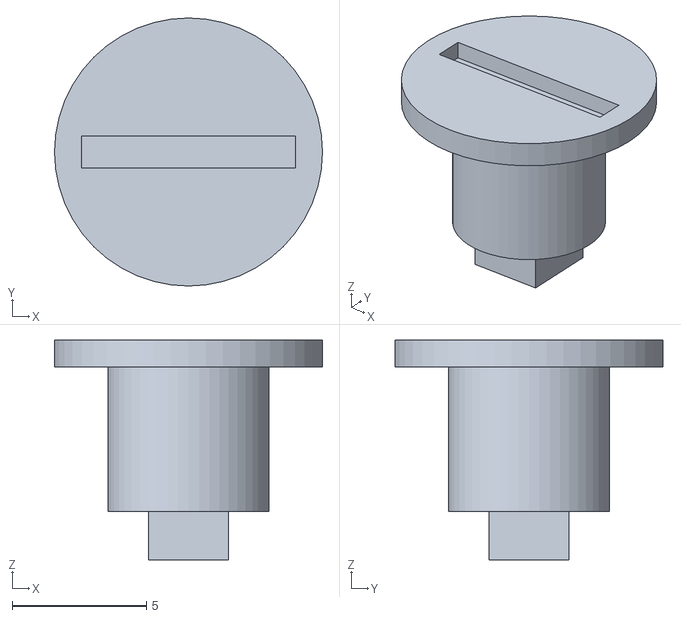
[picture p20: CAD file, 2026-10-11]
cad/gabinete/trava-botao.stl
10.0 x 10.0 x 8.20

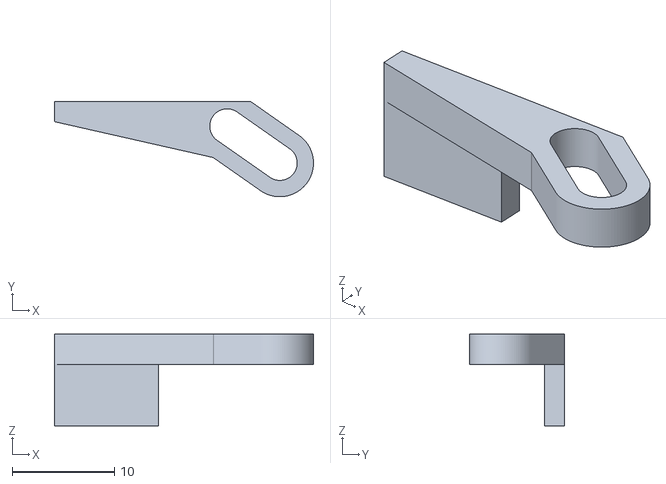
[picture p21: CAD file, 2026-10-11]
cad/alavanca-tampa.stl
25.4 x 9.35 x 9.00

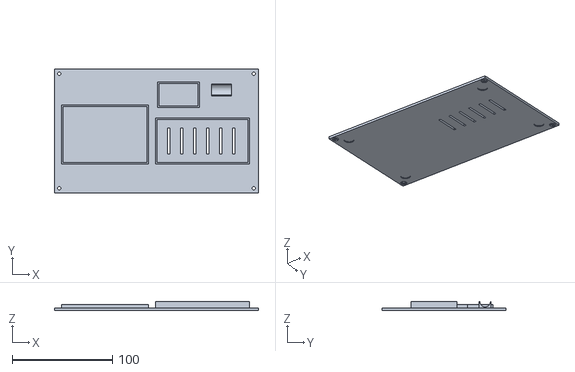
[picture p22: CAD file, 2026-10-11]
cad/gabinete/fundo.stl
203.4 x 123.4 x 8.50

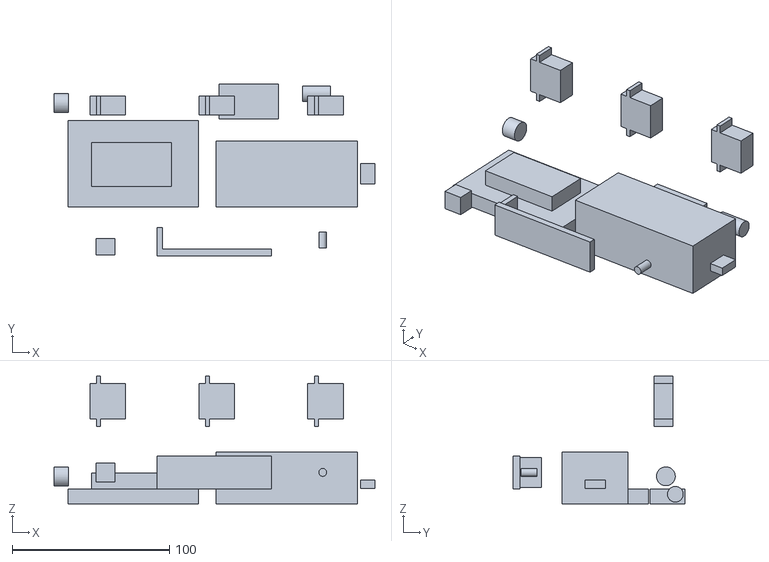
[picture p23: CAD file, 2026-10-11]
cad/gabinete/componentes.stl
204.0 x 109.0 x 81.2

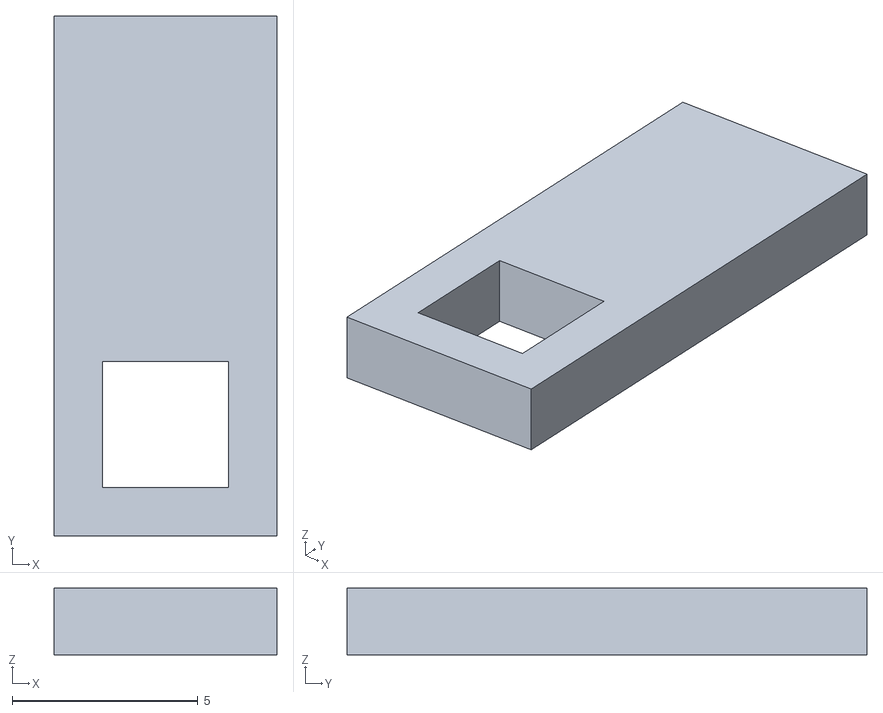
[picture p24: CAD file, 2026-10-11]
cad/gabinete/trava-lingueta.stl
6.00 x 14.0 x 1.80

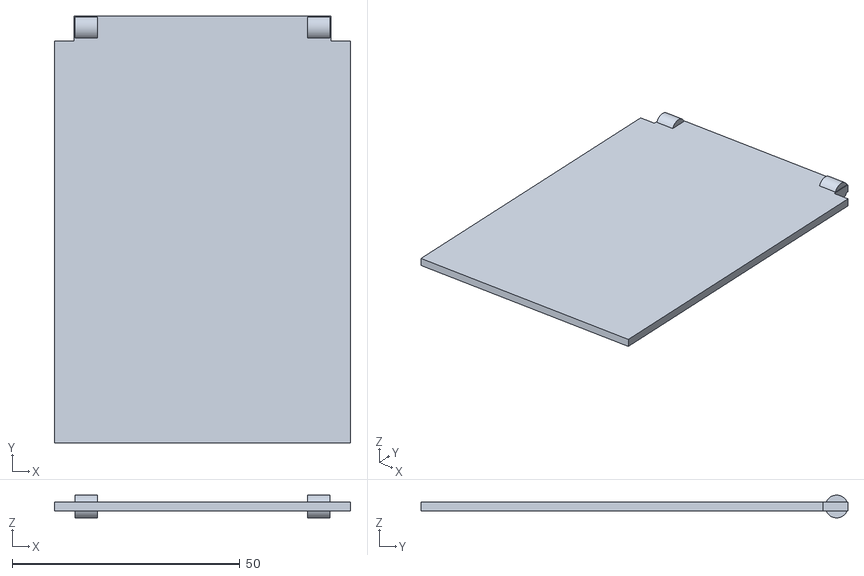
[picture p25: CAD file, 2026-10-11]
cad/gabinete/tampa-compartimento.stl
65.0 x 93.7 x 5.00

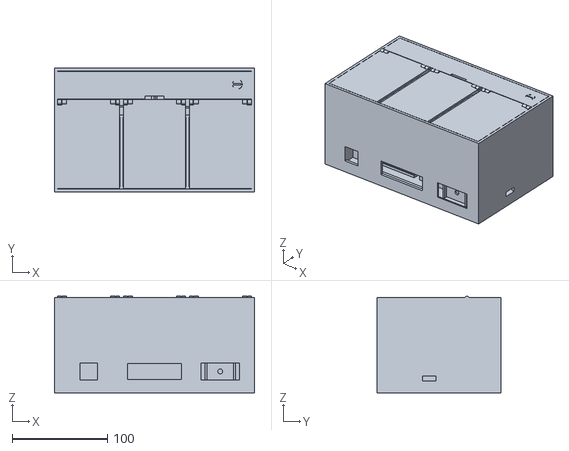
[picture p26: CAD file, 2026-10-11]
cad/gabinete/montagem.stl
210.0 x 130.0 x 101.5

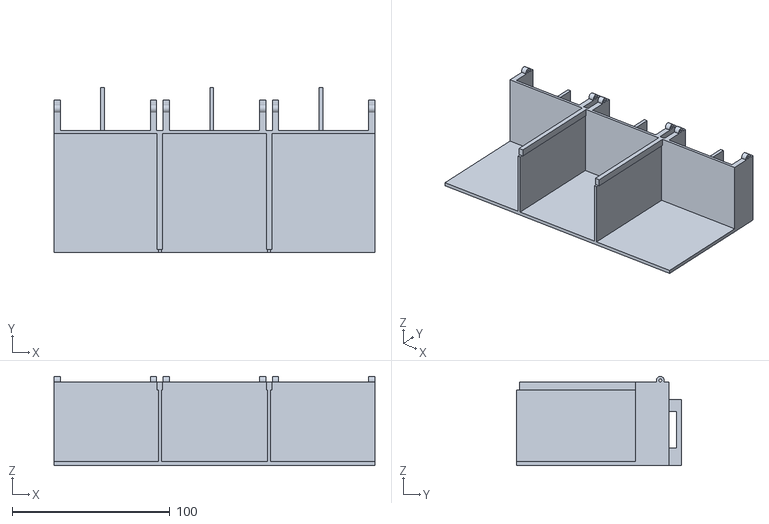
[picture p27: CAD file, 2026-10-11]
cad/gabinete/bandeja.stl
203.4 x 104.7 x 56.5

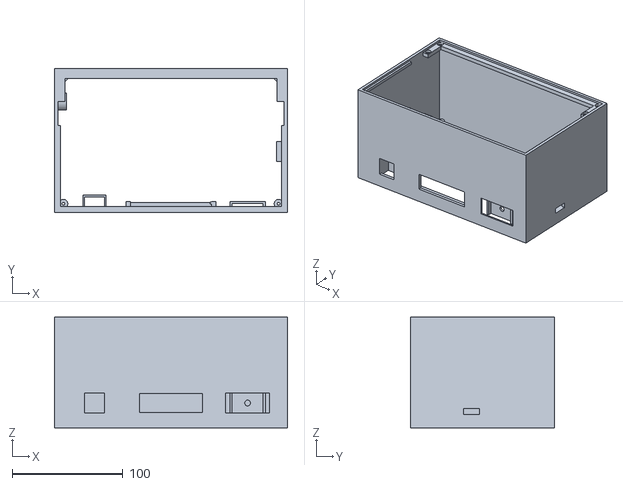
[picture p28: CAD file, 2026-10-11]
cad/gabinete/corpo.stl
210.0 x 130.0 x 100.0

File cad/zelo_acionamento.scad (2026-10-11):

// Zelo+ — Acionamento da tampa do compartimento (impressao 3D)
// Pecas: alavanca da tampa, braco do servo e pino com argola.
// Abra no OpenSCAD, escolha a peca em PECA e exporte o STL (F6, depois F7).
//
// Montagem (corte lateral; Y para tras e Z para cima, em mm a partir da frente e da base):
//   eixo da dobradica da tampa ........ Y 94,5  Z 99   (13,8 mm atras da divisoria)
//   eixo do servo SG90 ................. Y 98,5  Z 73   (eixo paralelo ao da dobradica)
//   furo do pino no braco do servo ..... a 20 mm do eixo do servo
//   rasgo da alavanca .................. de 6,0 a 12,3 mm do eixo da dobradica, a -35 graus
//   curso do servo ..................... 47 graus para a tampa ir de 0 a 90 graus

PECA = "alavanca";   // "alavanca", "braco" ou "pino"

PHI0 = -35;            // angulo da alavanca com a tampa fechada
R_BRACO = 20;          // raio do furo do pino no braco do servo
RASGO_INI = 6.0;
RASGO_FIM = 12.3;
FURO = 3.4;            // folga para o pino de 3,0 mm
PAREDE = 1.6;
ESP_ALAVANCA = 3.0;
ESP_BRACO = 3.2;
PINO_D = 3.0;
// braco simples original do SG90 (encaixe)
HORN_L = 15.5;  HORN_CUBO = 3.8;  HORN_PONTA = 2.3;

$fn = 96;
u = [cos(PHI0), sin(PHI0)];
function ao_longo(r) = r * u;
rb = FURO / 2 + PAREDE;

module bossa()  { hull() { translate(ao_longo(RASGO_INI)) circle(rb); translate(ao_longo(RASGO_FIM)) circle(rb); } }
module rasgo()  { hull() { translate(ao_longo(RASGO_INI)) circle(FURO / 2); translate(ao_longo(RASGO_FIM)) circle(FURO / 2); } }
module sapata() { translate([-12, -3]) square([10.2, 2]); }   // face de colagem em Z = -1

module alavanca() {
  linear_extrude(ESP_ALAVANCA)
    difference() {
      intersection() {
        union() { sapata(); hull() { sapata(); translate(ao_longo(RASGO_INI)) circle(rb); } bossa(); }
        translate([-20, -30]) square([50, 29]);            // nada acima de Z = -1
      }
      rasgo();
    }
  translate([0, 0, -6]) linear_extrude(9) sapata();           // sapata de 9 mm para a cola
}

module braco() {
  difference() {
    linear_extrude(ESP_BRACO) hull() { circle(6); translate([R_BRACO, 0]) circle(4); }
    translate([0, 0, -1]) cylinder(h = ESP_BRACO + 2, r = 2.9);              // acesso ao parafuso central
    translate([R_BRACO, 0, -1]) cylinder(h = ESP_BRACO + 2, d = FURO);       // furo do pino
    translate([0, 0, ESP_BRACO - 1.6]) linear_extrude(2)                     // encaixe do braco original
      hull() { circle(HORN_CUBO + 0.2); translate([HORN_L, 0]) circle(HORN_PONTA + 0.2); }
    for (r = [8, 12]) translate([r, 0, -1]) cylinder(h = ESP_BRACO + 2, r = 0.65);  // parafusos M2
  }
}

module pino() {
  L = ESP_ALAVANCA + 0.5 + ESP_BRACO + 2.6;   // alavanca + folga + braco + trava
  ez = PINO_D / 2 - 0.3;                       // base plana de 0,3 mm na mesa
  intersection() {
    union() {
      difference() {
        union() {
          translate([0, 0, ez]) rotate([0, 90, 0]) cylinder(h = L, d = PINO_D);
          translate([L - 1.2, 0, ez]) rotate([0, 90, 0]) cylinder(h = 1.2, r1 = PINO_D / 2 + 0.35, r2 = PINO_D / 2 - 0.4);
        }
        translate([L - 4.2, -0.4, -2]) cube([4.3, 0.8, 10]);   // fenda: as metades flexionam ao encaixar
      }
      translate([-1, 0, ez]) rotate([0, 90, 0]) cylinder(h = 1, r = PINO_D / 2 + 1);
      translate([-1 - 6 + 0.6, 0, 0]) linear_extrude(2.4) difference() { circle(6); circle(3.6); }
    }
    translate([-50, -50, 0]) cube([100, 100, 50]);
  }
}

if (PECA == "alavanca") alavanca();
if (PECA == "braco") braco();
if (PECA == "pino") pino();

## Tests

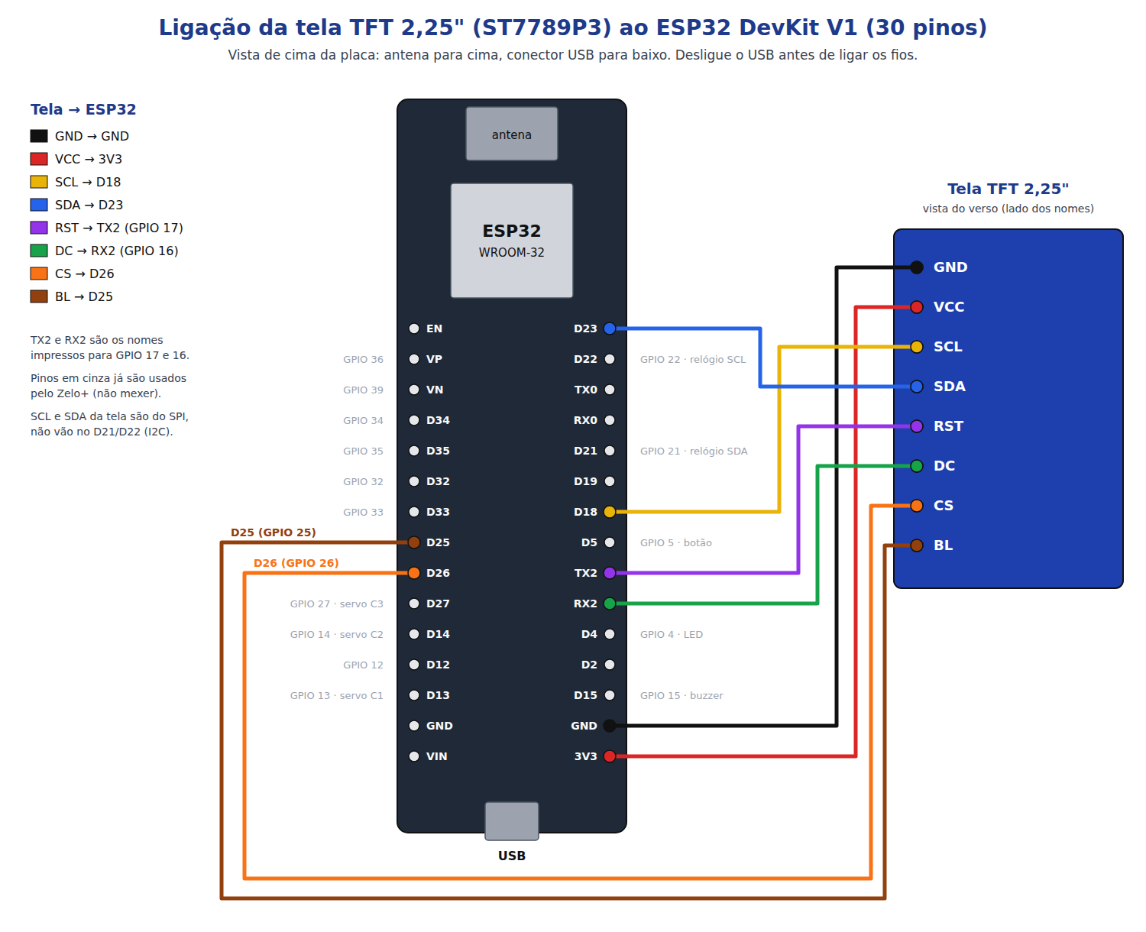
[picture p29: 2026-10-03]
docs/ligacoes-teste-tela.png

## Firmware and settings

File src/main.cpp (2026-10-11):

#include <Arduino.h>
#include <WiFi.h>
#include <WiFiClientSecure.h>
#include <HTTPClient.h>
#include <ArduinoJson.h>
#include <WebServer.h>
#include <DNSServer.h>
#include <Preferences.h>
#include <time.h>
#include <Wire.h>
#include <SPI.h>
#include <Adafruit_GFX.h>
#include <Adafruit_ST7789.h>
#include <U8g2_for_Adafruit_GFX.h>
#include <ESP32Servo.h>
#include <RTClib.h>
#include <esp_sntp.h>

#define BUZZER_PIN 15
#define LED_PIN 4
#define BUTTON_PIN 5
#define NUM_COMPARTIMENTOS 3
#define MAX_HORARIOS 6       // horarios por medicamento
#define MAX_FAMILIARES 5
#define MAX_HISTORICO 60

// Um servo por compartimento. O GPIO 12 foi evitado de proposito: ele interfere
// na inicializacao do ESP32.
const int PINOS_SERVO[NUM_COMPARTIMENTOS] = {13, 14, 27};
// Angulos de cada porta (ajuste aqui se algum mecanismo precisar de outro valor).
const int ANGULO_FECHADO[NUM_COMPARTIMENTOS] = {0, 0, 0};
const int ANGULO_ABERTO[NUM_COMPARTIMENTOS] = {90, 90, 90};

// Cor de cada compartimento na pagina (use etiquetas das mesmas cores na caixa).
const char* COR_COMPARTIMENTO[NUM_COMPARTIMENTOS] = {"#2563eb", "#16a34a", "#9333ea"};
const char* FUNDO_COMPARTIMENTO[NUM_COMPARTIMENTOS] = {"#eff6ff", "#f0fdf4", "#faf5ff"};
const char* NOME_COR[NUM_COMPARTIMENTOS] = {"azul", "verde", "roxo"};

// Visor: tela TFT 2,25" colorida (controlador ST7789P3, 76 x 284 pontos), ligada
// por SPI (SCL -> GPIO 18, SDA -> GPIO 23). A luz de fundo deste modulo acende
// com o pino BL em nivel BAIXO.
#define TELA_CS 26
#define TELA_DC 16
#define TELA_RST 17
#define TELA_BL 25
Adafruit_ST7789 tela(TELA_CS, TELA_DC, TELA_RST);
U8G2_FOR_ADAFRUIT_GFX texto;
Servo servos[NUM_COMPARTIMENTOS];
// Sinal de brilho da tela. Fica com a biblioteca dos servos, que escolhe um canal
// e um temporizador livres: os servos usam 50 Hz e a luz de fundo 5.000 Hz, e os
// dois nao podem dividir o mesmo temporizador do ESP32.
ESP32PWM luzVisor;
WebServer server(80);
DNSServer dnsServer;
Preferences preferences;
Preferences prefsCadastro;
Preferences prefsHistorico;

const byte DNS_PORT = 53;
IPAddress apIP(192, 168, 4, 1);

const char* ntpServer = "pool.ntp.org";
const long gmtOffset_sec = -10800; // Brasília (GMT-3)
const int daylightOffset_sec = 0;

bool modoConfig = false;
bool modoLocal = false;  // sem internet: o dispenser usa a propria rede
bool servidorNoAr = false;

// Rede propria aberta automaticamente quando a rede salva nao conecta ao ligar.
const char* NOME_REDE_LOCAL = "ZeloPlus";
const char* SENHA_REDE_LOCAL = "zelo1234";
const unsigned long INTERVALO_NOVA_TENTATIVA = 10UL * 60UL * 1000UL; // 10 min
const unsigned long DURACAO_TENTATIVA = 20000;
String nomeRedeLocal = "";      // ZeloPlus (automatica) ou ZeloPlus-Config (pela configuracao)
String motivoSemInternet = "";  // mostrado no aviso da pagina
String redeSalva = "";
String senhaRedeSalva = "";
bool tentandoRede = false;
unsigned long tentativaIniciadaEm = 0;
String configErro = "";

// ---------- RELOGIO DS3231 (opcional) ----------
// Modulo de relogio ligado no I2C (endereco 0x68). Guarda a hora
// certa mesmo sem internet e sem energia. Sem o modulo, tudo funciona como antes,
// com a hora vinda da internet (NTP).
RTC_DS3231 rtc;
bool rtcPresente = false;             // o modulo respondeu no I2C ao ligar
bool horaDoRtc = false;               // a hora atual veio do DS3231 ao ligar
volatile bool ntpSincronizou = false; // avisado pelo NTP a cada acerto de hora
const uint32_t HORA_MINIMA_VALIDA = 1704067200UL; // 01/01/2024: antes disso, hora invalida

// Contato que recebe avisos pelo Telegram. O chatId e o numero que o Telegram
// usa para identificar a conversa da pessoa com o bot do Zelo+ (a pessoa precisa
// abrir o bot e tocar em "Iniciar" uma vez).
struct Contato {
  String nome;
  String telefone;
  String chatId;
};

// Medicamento guardado num compartimento fixo (indice 0..2 = compartimento 1..3).
struct Medicamento {
  String nome;
  int totalHorarios = 0;
  int hora[MAX_HORARIOS];
  int minuto[MAX_HORARIOS];
  bool jaDisparado[MAX_HORARIOS];
};

String nomePaciente = "";
Medicamento medicamentos[NUM_COMPARTIMENTOS];
Contato cuidador;
Contato familiares[MAX_FAMILIARES];
String tokenTelegram = ""; // token do bot, criado pelo cuidador no @BotFather
String chaveIA = "";       // chave da API do Gemini (leitura da caixa por foto)
const char* MODELO_IA_PADRAO = "gemini-3.5-flash";
String modeloIA = MODELO_IA_PADRAO; // modelo do Gemini usado na leitura
int ultimoMinutoChecado = -1;

const unsigned long TEMPO_PORTA_ABERTA = 3UL * 60UL * 1000UL;
const unsigned long TEMPO_ABASTECIMENTO = 3UL * 60UL * 1000UL;
const unsigned long TRAVA_BOTAO = 7UL * 1000UL; // 7 segundos de trava apos abrir

// Ciclo do alarme: 1 min tocando, 1 min em silencio, repetindo.
// Aos 6 min sem acesso avisa o cuidador; aos 12 min para de tocar e alerta
// cuidador + familiares.
// MODO_TESTE encurta os tempos para testar em bancada: aviso aos 30 s, alerta
// final aos 60 s e ciclo de 5 s tocando / 5 s em silencio (mesma proporcao do
// modo real). Mude para 0 antes de usar de verdade.
#define MODO_TESTE 1

#if MODO_TESTE
const unsigned long CICLO_ALARME = 5UL * 1000UL;
const unsigned long TEMPO_PRIMEIRO_AVISO = 30UL * 1000UL;
const unsigned long TEMPO_ALERTA_FINAL = 60UL * 1000UL;
#else
const unsigned long CICLO_ALARME = 60UL * 1000UL;
const unsigned long TEMPO_PRIMEIRO_AVISO = 6UL * 60UL * 1000UL;
const unsigned long TEMPO_ALERTA_FINAL = 12UL * 60UL * 1000UL;
#endif

enum Estado { AGUARDANDO, TOCANDO, PORTA_ABERTA_ESTADO, ABASTECENDO, MODO_CUIDADOR };
Estado estadoAtual = AGUARDANDO;

// Motivo da abertura no estado ABASTECENDO (so muda o texto do visor).
enum ModoAbastecimento { ABAST_NOVO, ABAST_REPOR, ABAST_ESVAZIAR };
ModoAbastecimento modoAbastecimento = ABAST_NOVO;
int compartimentoAbastecendo = -1;
uint8_t filaAbastecimento = 0; // compartimentos novos esperando para abrir (bits)

uint8_t mascaraAberta = 0;     // compartimentos com a porta aberta agora (bits)
unsigned long portaAbertaEm = 0;
unsigned long abastecimentoAbertoEm = 0;
unsigned long ultimoToggleAlarme = 0;
bool ledBuzzerLigado = false;

// Dose atual: compartimentos que tocaram juntos no mesmo horario.
uint8_t doseMascara = 0;
String horarioDose = "";
String nomesDose = "";
unsigned long alarmeIniciadoEm = 0;
int nivelAvisoEnviado = 0;   // 0 = nenhum, 1 = cuidador avisado, 2 = todos alertados
bool dosePendente = false;   // alarme terminou sem acesso; botao ainda abre os compartimentos

// Modo do cuidador: abre qualquer compartimento pelo botao, sem o celular.
// Entra segurando o botao por TEMPO_ENTRAR_CUIDADOR fora do horario de dose;
// toque curto passa para a proxima opcao, toque longo confirma.
const unsigned long TEMPO_ENTRAR_CUIDADOR = 10000;
const unsigned long TEMPO_CONFIRMAR_OPCAO = 1500;
const unsigned long TEMPO_SAIR_CUIDADOR = 30000; // sem uso, volta sozinho
unsigned long botaoApertadoEm = 0;   // 0 = botao solto
bool aguardandoSoltarBotao = false;  // ignora o toque que acabou de entrar no modo
bool avisoSegurarMostrado = false;   // visor ja mostra "Segure mais N s"
int opcaoCuidador = 0;               // 0..2 = compartimento, 3 = sair
unsigned long ultimaAcaoCuidador = 0;

// Horarios que chegaram enquanto o dispenser estava ocupado: tocam assim que
// ele voltar a ficar livre.
uint8_t mascaraEmEspera = 0;
String horarioEmEspera = "";

bool temBit(uint8_t mascara, int i) {
  return (mascara >> i) & 1;
}

bool medicamentoAtivo(int c) {
  return medicamentos[c].nome != "" && medicamentos[c].totalHorarios > 0;
}

int totalMedicamentosAtivos() {
  int total = 0;
  for (int c = 0; c < NUM_COMPARTIMENTOS; c++) {
    if (medicamentoAtivo(c)) total++;
  }
  return total;
}

// ---------- PORTAS (servos) ----------
// Nunca move dois servos ao mesmo tempo, para nao sobrecarregar a fonte.

// Duracao de cada movimento de porta (abrir ou fechar), em milissegundos.
// Aumente para deixar as portas mais lentas.
const unsigned long TEMPO_MOVIMENTO_PORTA = 7000;

// Largura do pulso do servo em 0 e em 180 graus (padrao do SG90/MG90).
const int PULSO_0_GRAU = 544;
const int PULSO_180_GRAUS = 2400;

// Resolucao do sinal dos servos: 16 bits dao cerca de 0,3 us por unidade (o
// padrao, 10 bits, so tem cerca de 20 us, quase 2 graus).
const int RESOLUCAO_SERVO = 16;

int pulsoDoAngulo(float angulo) {
  return PULSO_0_GRAU + (int)round(angulo * (PULSO_180_GRAUS - PULSO_0_GRAU) / 180.0);
}

// Move a porta devagar e sem trancos: comeca lento, acelera no meio e freia no
// fim (curva de cosseno). Um passo a cada 20 ms, o intervalo do sinal do servo.
// Exige os servos em 5 V: com tensao baixa eles nao tem forca para os avancos
// pequenos, param zumbindo e depois saltam.
void moverPorta(int c, int de, int para) {
  const int passos = TEMPO_MOVIMENTO_PORTA / 20;
  for (int i = 1; i <= passos; i++) {
    float t = (float)i / passos;          // 0 -> 1 ao longo do movimento
    float suave = (1 - cos(t * PI)) / 2;  // 0 -> 1, lento no inicio e no fim
    servos[c].writeMicroseconds(pulsoDoAngulo(de + (para - de) * suave));
    delay(20);
  }
}

void abrirCompartimento(int c) {
  moverPorta(c, ANGULO_FECHADO[c], ANGULO_ABERTO[c]);
}

void fecharCompartimento(int c) {
  moverPorta(c, ANGULO_ABERTO[c], ANGULO_FECHADO[c]);
}

// Abre os compartimentos marcados, um logo apos o outro.
void abrirCompartimentos(uint8_t mascara) {
  for (int c = 0; c < NUM_COMPARTIMENTOS; c++) {
    if (temBit(mascara, c)) abrirCompartimento(c);
  }
}

void fecharCompartimentos(uint8_t mascara) {
  for (int c = 0; c < NUM_COMPARTIMENTOS; c++) {
    if (temBit(mascara, c)) fecharCompartimento(c);
  }
}

// ---------- TEXTO ----------

// Escapa caracteres especiais antes de inserir texto do usuario (ou nomes de
// redes Wi-Fi) no HTML, para que aspas ou tags nao quebrem a pagina.
String escaparHTML(const String& texto) {
  String saida;
  saida.reserve(texto.length() + 8);
  for (unsigned int i = 0; i < texto.length(); i++) {
    char c = texto[i];
    switch (c) {
      case '&': saida += "&amp;"; break;
      case '<': saida += "&lt;"; break;
      case '>': saida += "&gt;"; break;
      case '"': saida += "&quot;"; break;
      case '\'': saida += "&#39;"; break;
      default: saida += c;
    }
  }
  return saida;
}

// ---------- VISOR ----------

const int VISOR_LARGURA = 284;
const int VISOR_ALTURA = 76;

// Cores do visor (RGB). Os compartimentos usam as mesmas cores da pagina.
const uint32_t COR_PRETO = 0x000000;
const uint32_t COR_BRANCO = 0xFFFFFF;
const uint32_t COR_AMARELO = 0xFACC15;
const uint32_t COR_VERDE = 0x16A34A;
const uint32_t COR_VERMELHO = 0xDC2626;
const uint32_t COR_LARANJA = 0xEA580C;
const uint32_t COR_CINZA = 0x4B5563;
const uint32_t COR_AZUL_ESCURO = 0x1E3A8A;
const uint32_t COR_VISOR_COMPARTIMENTO[NUM_COMPARTIMENTOS] = {0x2563EB, 0x16A34A, 0x9333EA};

uint32_t corFundo = COR_PRETO;
uint32_t corLinha[2] = {COR_BRANCO, COR_BRANCO};
String linhaMostrada[2];
bool telaEsperaDesenhada = false;

uint16_t cor565(uint32_t rgb) {
  return tela.color565((rgb >> 16) & 0xFF, (rgb >> 8) & 0xFF, rgb & 0xFF);
}

// Brilho de 0 a 100 %. O pino BL acende em nivel baixo: 100 % = pino em 0.
void brilhoVisor(int porcento) {
  luzVisor.write((100 - porcento) * 255 / 100);
}

// Troca a fonte mantendo o texto transparente (a biblioteca volta a pintar o
// fundo das letras a cada troca de fonte).
void fonteVisor(const uint8_t* fonte) {
  texto.setFont(fonte);
  texto.setFontMode(1);
}

// Cores da proxima tela: fundo e cor de cada linha. Vale a partir do
// proximo limparVisor().
void temaVisor(uint32_t fundo, uint32_t linha0 = COR_BRANCO, uint32_t linha1 = COR_BRANCO) {
  corFundo = fundo;
  corLinha[0] = linha0;
  corLinha[1] = linha1;
}

void limparVisor() {
  tela.fillScreen(cor565(corFundo));
  linhaMostrada[0] = "\x01";
  linhaMostrada[1] = "\x01";
  telaEsperaDesenhada = false;
}

// Confere, na partida, se a luz de fundo da tela ficou num temporizador
// diferente do dos servos. No ESP32, os canais de PWM andam em pares (0-1, 2-3,
// ...), e cada par divide o mesmo temporizador e a mesma frequencia: servo
// (50 Hz) e luz de fundo (5.000 Hz) no mesmo par fariam o servo parar.
void conferirCanaisPWM(const int canalServo[]) {
  int canalLuz = luzVisor.getChannel();
  Serial.printf("PWM: servos C1, C2, C3 nos canais %d, %d, %d (50 Hz); luz da tela no canal %d (5 kHz)\n",
                canalServo[0], canalServo[1], canalServo[2], canalLuz);
  for (int c = 0; c < NUM_COMPARTIMENTOS; c++) {
    if (canalServo[c] < 0) {
      Serial.printf("ERRO: o servo do compartimento %d nao conseguiu canal de PWM\n", c + 1);
    } else if (canalServo[c] / 2 == canalLuz / 2) {
      Serial.printf("ERRO: o servo do compartimento %d divide o temporizador com a luz da tela\n", c + 1);
    }
  }
}

void iniciarVisor() {
  luzVisor.attachPin(TELA_BL, 5000, 8);
  brilhoVisor(100);
  tela.init(VISOR_ALTURA, VISOR_LARGURA); // o painel e "em pe": 76 x 284
  tela.setRotation(1);                    // deitado: 284 x 76
  tela.invertDisplay(false);              // este painel nao usa inversao de cores
  texto.begin(tela);
  temaVisor(COR_PRETO);
  limparVisor();
}

// Prepara o texto para o visor: corta em 'maxLetras' letras (sem partir os
// acentos) e, com maiusculas = true (nomes dos remedios), passa tudo para
// maiusculas, inclusive as letras acentuadas ("Losartana Potássica" ->
// "LOSARTANA POTÁSSICA").
String textoVisor(const String& original, unsigned int maxLetras = 40, bool maiusculas = false) {
  String saida;
  unsigned int letras = 0;
  for (unsigned int i = 0; i < original.length() && letras < maxLetras; i++) {
    uint8_t c = (uint8_t)original[i];
    if (c == 0xC3 && i + 1 < original.length()) {
      uint8_t segundo = (uint8_t)original[++i];
      if (maiusculas && segundo >= 0xA0 && segundo <= 0xBE && segundo != 0xB7) segundo -= 0x20;
      saida += (char)c;
      saida += (char)segundo;
    } else if (c >= 0x80) {
      saida += (char)c;
      while (i + 1 < original.length() && ((uint8_t)original[i + 1] & 0xC0) == 0x80) saida += original[++i];
    } else {
      saida += maiusculas ? (char)toupper(c) : (char)c;
    }
    letras++;
  }
  return saida;
}

// Escreve uma das duas linhas do visor, centralizada: linha 0 (em cima, letra
// menor) ou linha 1 (embaixo, letra maior, para o nome do remedio). Se o texto
// nao couber, a letra diminui. So redesenha quando o texto muda.
void escreverLinha(int linha, const String& conteudo) {
  if (conteudo == linhaMostrada[linha]) return;
  linhaMostrada[linha] = conteudo;

  int topo = (linha == 0) ? 0 : 34;
  int altura = (linha == 0) ? 34 : 42;
  tela.fillRect(0, topo, VISOR_LARGURA, altura, cor565(corFundo));

  const uint8_t* fontes[3] = {u8g2_font_helvB24_tf, u8g2_font_helvB18_tf, u8g2_font_helvB14_tf};
  int primeira = (linha == 0) ? 1 : 0;
  for (int f = primeira; f < 3; f++) {
    fonteVisor(fontes[f]);
    if (texto.getUTF8Width(conteudo.c_str()) <= VISOR_LARGURA - 8 || f == 2) break;
  }
  // Ainda grande demais na menor letra: corta o final e poe "..."
  String mostrar = conteudo;
  while (texto.getUTF8Width(mostrar.c_str()) > VISOR_LARGURA - 8 && mostrar.length() > 4) {
    if (mostrar.endsWith("...")) mostrar.remove(mostrar.length() - 3);
    int fim = mostrar.length() - 1;
    while (fim > 0 && ((uint8_t)mostrar[fim] & 0xC0) == 0x80) fim--; // nao parte letras acentuadas
    mostrar.remove(fim);
    mostrar.trim();
    mostrar += "...";
  }
  int largura = texto.getUTF8Width(mostrar.c_str());
  int base = topo + (altura + texto.getFontAscent()) / 2;
  texto.setForegroundColor(cor565(corLinha[linha]));
  texto.drawUTF8((VISOR_LARGURA - largura) / 2, base, mostrar.c_str());
}
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
void loop() {
  if (modoConfig || modoLocal) {
    dnsServer.processNextRequest();
  }
  server.handleClient();

  if (modoConfig) {
    return;
  }

  manterWiFi();
  gravarHoraNoRTC();
  verificarHorarios();

  switch (estadoAtual) {
    case AGUARDANDO:
      if (dosePendente && digitalRead(BUTTON_PIN) == LOW) {
        abrirParaPaciente();
        break;
      }
      // Prioridade: alarme em espera; depois abastecimento de compartimento novo.
      if (mascaraEmEspera != 0) {
        uint8_t mascara = mascaraEmEspera;
        mascaraEmEspera = 0;
        iniciarAlarme(mascara, horarioEmEspera);
        break;
      }
      if (filaAbastecimento != 0) {
        for (int c = 0; c < NUM_COMPARTIMENTOS; c++) {
          if (!temBit(filaAbastecimento, c)) continue;
          filaAbastecimento &= (uint8_t)~(1 << c);
          iniciarAbastecimento(c, ABAST_NOVO);
          break;
        }
        break;
      }
      if (!dosePendente && acompanharBotaoEspera()) break;
      atualizarTelaEspera();
      break;

    case TOCANDO: {
      unsigned long decorrido = millis() - alarmeIniciadoEm;

      if (digitalRead(BUTTON_PIN) == LOW) {
        abrirParaPaciente();
        break;
      }

      if (decorrido >= TEMPO_ALERTA_FINAL) {
        desligarLedBuzzer();
        temaVisor(COR_VERMELHO);
        limparVisor();
        escreverLinha(0, "Avisando a família");
        atualizarDose(DOSE_SEM_ACESSO, decorrido);
        alertarSemAcesso();
        nivelAvisoEnviado = 2;

        // Para de tocar, mas o botao continua abrindo os compartimentos da dose.
        // Os registros continuam ligados a dose para virar "com atraso" se o
        // paciente ainda aparecer.
        dosePendente = true;
        limparVisor();
        estadoAtual = AGUARDANDO;
        break;
      }

      if (decorrido >= TEMPO_PRIMEIRO_AVISO && nivelAvisoEnviado == 0) {
        desligarLedBuzzer();
        escreverLinha(1, "Avisando o cuidador");
        avisarPrimeiroAtraso();
        nivelAvisoEnviado = 1;
      }

      // Nome e compartimento de cada remedio da dose, alternando a cada 2 s; o
      // fundo do visor fica na cor do compartimento mostrado.
      static unsigned long ultimaTrocaNome = 0;
      static int nomeMostrado = -1;
      if (millis() - ultimaTrocaNome >= 2000 || nomeMostrado < 0 || !temBit(doseMascara, nomeMostrado)) {
        ultimaTrocaNome = millis();
        for (int passo = 1; passo <= NUM_COMPARTIMENTOS; passo++) {
          int c = (nomeMostrado + passo + NUM_COMPARTIMENTOS) % NUM_COMPARTIMENTOS;
          if (!temBit(doseMascara, c)) continue;
          if (c != nomeMostrado) mostrarAlarme(c);
          nomeMostrado = c;
          escreverLinha(1, textoVisor(medicamentos[c].nome, 40, true));
          break;
        }
      }

      bool minutoDeSom = ((decorrido / CICLO_ALARME) % 2) == 0;
      if (!minutoDeSom) {
        if (ledBuzzerLigado) desligarLedBuzzer();
        break;
      }

      if (millis() - ultimoToggleAlarme >= 150) {
        ultimoToggleAlarme = millis();
        ledBuzzerLigado = !ledBuzzerLigado;
        digitalWrite(LED_PIN, ledBuzzerLigado ? HIGH : LOW);
        digitalWrite(BUZZER_PIN, ledBuzzerLigado ? HIGH : LOW);
      }
      break;
    }

    case PORTA_ABERTA_ESTADO: {
      static unsigned long ultimaAtualizacaoContagem = 0;

      bool travaLiberada = (millis() - portaAbertaEm >= TRAVA_BOTAO);
      bool fechar = (travaLiberada && digitalRead(BUTTON_PIN) == LOW) ||
                    (millis() - portaAbertaEm >= TEMPO_PORTA_ABERTA);

      if (fechar) {
        temaVisor(COR_PRETO);
        limparVisor();
        escreverLinha(0, "Fechando a porta...");
        fecharCompartimentos(mascaraAberta);
        mascaraAberta = 0;

        limparVisor();
        estadoAtual = AGUARDANDO;
        break;
      }

      if (millis() - ultimaAtualizacaoContagem >= 500) {
        ultimaAtualizacaoContagem = millis();
        escreverLinha(0, "Retire: " + listaCompartimentos(mascaraAberta));
        mostrarContagem(portaAbertaEm, TEMPO_PORTA_ABERTA);
      }
      break;
    }

    case MODO_CUIDADOR:
      atenderModoCuidador();
      break;

    case ABASTECENDO: {
      static unsigned long ultimaAtualizacaoAbastecimento = 0;

      bool travaLiberada = (millis() - abastecimentoAbertoEm >= TRAVA_BOTAO);
      bool fechar = (travaLiberada && digitalRead(BUTTON_PIN) == LOW) ||
                    (millis() - abastecimentoAbertoEm >= TEMPO_ABASTECIMENTO);

      if (fechar) {
        temaVisor(COR_PRETO);
        limparVisor();
        escreverLinha(0, "Fechando a porta...");
        fecharCompartimentos(mascaraAberta);
        mascaraAberta = 0;
        compartimentoAbastecendo = -1;

        limparVisor();
        estadoAtual = AGUARDANDO; // o proximo da fila (se houver) abre pelo loop()
        break;
      }

      // A linha de baixo alterna entre o nome do remedio e a contagem, a cada 2 s,
      // depois da trava.
      if (millis() - ultimaAtualizacaoAbastecimento >= 1000) {
        ultimaAtualizacaoAbastecimento = millis();
        unsigned long decorrido = millis() - abastecimentoAbertoEm;
        bool mostrarNome = !travaLiberada || (decorrido / 2000) % 2 == 0;
        if (mostrarNome) {
          escreverLinha(1, modoAbastecimento == ABAST_ESVAZIAR ? String("Retire tudo")
                                                               : textoVisor(medicamentos[compartimentoAbastecendo].nome, 22, true));
        } else {
          mostrarContagem(abastecimentoAbertoEm, TEMPO_ABASTECIMENTO);
        }
      }
      break;
    }
  }
}

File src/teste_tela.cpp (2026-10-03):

// Programa de TESTE da tela TFT 2,25" (controlador ST7789P3, 76 x 284 pontos).
// Fica separado do firmware do Zelo+: no PlatformIO, escolha o ambiente
// "env:teste-tela" para gravar este teste e "env:esp32dev" para voltar ao Zelo+.
//
// Ligacao (SPI):
//   GND -> GND      VCC -> 3V3
//   SCL -> GPIO 18  SDA -> GPIO 23   (relogio e dados do SPI, nao e I2C)
//   RST -> GPIO 17  DC  -> GPIO 16   CS -> GPIO 26   BL -> GPIO 25 (luz de fundo,
//   acende em nivel baixo)
//
// O que o teste mostra, em sequencia:
//   1. Tela inteira VERMELHA, VERDE e AZUL (confere as cores).
//   2. Telas do Zelo+: em dia, dose pendente, alarme, retirada.
//   3. Acentos e brilho reduzido (luz de fundo a 30 %).

#include <Arduino.h>
#include <SPI.h>
#include <Adafruit_GFX.h>
#include <Adafruit_ST7789.h>
#include <U8g2_for_Adafruit_GFX.h>

#define TELA_CS 26
#define TELA_DC 16
#define TELA_RST 17
#define TELA_BL 25
#define CANAL_BRILHO 0

const int LARGURA = 284;
const int ALTURA = 76;

Adafruit_ST7789 tela(TELA_CS, TELA_DC, TELA_RST);
U8G2_FOR_ADAFRUIT_GFX texto;

uint16_t PRETO, BRANCO, VERDE, VERMELHO, AZUL, ROXO, AMARELO;

// Neste modulo a luz de fundo acende com o BL em nivel BAIXO (GND): o
// transistor do modulo inverte o sinal. Por isso 100 % de brilho = pino em 0.
void brilho(int porcento) {
  ledcWrite(CANAL_BRILHO, (100 - porcento) * 255 / 100);
}

// Troca a fonte mantendo o texto transparente: a biblioteca volta a pintar o
// fundo das letras a cada setFont, o que criava "caixinhas" atras do texto.
void fonte(const uint8_t* f) {
  texto.setFont(f);
  texto.setFontMode(1);
}

void escreverCentro(const char* s, int cx, int y) {
  int largura = texto.getUTF8Width(s);
  texto.drawUTF8(cx - largura / 2, y, s);
}

// Hora de exemplo (comeca em 08:30 e anda com o relogio do ESP32).
void horaExemplo(char* saida) {
  unsigned long minutos = 8 * 60 + 30 + millis() / 60000;
  sprintf(saida, "%02lu:%02lu", (minutos / 60) % 24, minutos % 60);
}

void telaCor(uint16_t cor, const char* nome) {
  tela.fillScreen(cor);
  fonte(u8g2_font_helvB24_tf);
  texto.setForegroundColor(BRANCO);
  escreverCentro(nome, LARGURA / 2, 50);
  Serial.printf("Cor: %s\n", nome);
}

// Hora grande a esquerda e caixa colorida com a situacao a direita.
void telaEspera(const char* linha1, const char* linha2, uint16_t corCaixa) {
  char hora[6];
  horaExemplo(hora);
  tela.fillScreen(PRETO);
  fonte(u8g2_font_logisoso50_tn);
  texto.setForegroundColor(BRANCO);
  texto.drawUTF8(6, 63, hora);
  tela.fillRoundRect(150, 6, 128, 64, 10, corCaixa);
  fonte(u8g2_font_helvB18_tf);
  escreverCentro(linha1, 214, 33);
  escreverCentro(linha2, 214, 59);
  Serial.printf("Espera: %s %s %s\n", hora, linha1, linha2);
}

void telaAlarme() {
  tela.fillScreen(AZUL);
  texto.setForegroundColor(BRANCO);
  fonte(u8g2_font_helvB18_tf);
  escreverCentro("Hora do remédio!", LARGURA / 2, 28);
  fonte(u8g2_font_helvB24_tf);
  escreverCentro("LOSARTANA (C1)", LARGURA / 2, 64);
  Serial.println("Alarme");
}

void telaRetirada() {
  tela.fillScreen(PRETO);
  fonte(u8g2_font_helvB24_tf);
  texto.setForegroundColor(BRANCO);
  escreverCentro("Retire: C1 C2", LARGURA / 2, 32);
  fonte(u8g2_font_helvB18_tf);
  texto.setForegroundColor(AMARELO);
  escreverCentro("Fecha em: 170s", LARGURA / 2, 64);
  Serial.println("Retirada");
}

void telaAcentos(int porcentoBrilho) {
  tela.fillScreen(PRETO);
  brilho(porcentoBrilho);
  fonte(u8g2_font_helvB18_tf);
  texto.setForegroundColor(BRANCO);
  escreverCentro("Medicação ç ã é ô í ú", LARGURA / 2, 30);
  char linha[24];
  sprintf(linha, "Brilho %d%%", porcentoBrilho);
  texto.setForegroundColor(ROXO);
  escreverCentro(linha, LARGURA / 2, 62);
  Serial.printf("Acentos, brilho %d%%\n", porcentoBrilho);
}

void setup() {
  Serial.begin(115200);
  Serial.println("Teste da tela TFT 2,25\" (ST7789P3, 76x284)");

  ledcSetup(CANAL_BRILHO, 5000, 8);
  ledcAttachPin(TELA_BL, CANAL_BRILHO);
  brilho(100);

  tela.init(ALTURA, LARGURA);  // a tela e "em pe": 76 de largura por 284 de altura
  tela.setRotation(1);         // deitada: 284 x 76
  tela.invertDisplay(false);   // este painel mostra as cores certas sem inversao
  texto.begin(tela);

  PRETO = tela.color565(0, 0, 0);
  BRANCO = tela.color565(255, 255, 255);
  VERDE = tela.color565(0x16, 0xa3, 0x4a);
  VERMELHO = tela.color565(0xdc, 0x26, 0x26);
  AZUL = tela.color565(0x25, 0x63, 0xeb);
  ROXO = tela.color565(0x93, 0x33, 0xea);
  AMARELO = tela.color565(0xfa, 0xcc, 0x15);
}

void loop() {
  telaCor(tela.color565(255, 0, 0), "VERMELHO");
  delay(2000);
  telaCor(tela.color565(0, 255, 0), "VERDE");
  delay(2000);
  telaCor(tela.color565(0, 0, 255), "AZUL");
  delay(2000);
  telaEspera("Medicação", "em dia", VERDE);
  delay(4000);
  telaEspera("Dose", "pendente!", VERMELHO);
  delay(4000);
  telaAlarme();
  delay(4000);
  telaRetirada();
  delay(4000);
  telaAcentos(100);
  delay(3000);
  telaAcentos(30);
  delay(3000);
  brilho(100);
}

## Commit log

2026-09-26 Adiciona firmware ESP32 do dispenser Zelo+ com cadastro persistente
    Importa o projeto PlatformIO do dispenser (zelo-plus/) a partir da
    documentação técnica e passa a salvar nome do idoso, remédio e horários
    em Preferences (namespace "cadastro"), recarregando no boot para que o
    cadastro sobreviva a reinícios e quedas de energia.
    Claude-Session: https://claude.ai/code/session_01EafyoyJ17WbY5Cu1vb7jso
2026-09-26 Corrige textos cortados no LCD e escapa HTML na página do Zelo+
    - Mensagens do LCD passam a caber em 16 colunas ("Conecte no Wi-Fi" /
    "ZeloPlus-Config", "Fechando porta..").
    - Nome do idoso, do remédio e SSIDs das redes são escapados antes de
    entrar no HTML, evitando que aspas ou tags quebrem a página.
    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
    [main.cpp]
2026-09-26 Adiciona contatos com WhatsApp e ciclo de avisos quando o paciente não aparece
    - Cadastro passa a usar "paciente" e inclui cuidador e até 2 familiares
    (nome, celular com WhatsApp e chave CallMeBot), salvos em Preferences.
    - Alarme toca em ciclos de 1 min tocando / 1 min em silêncio. Aos 6 min
    sem acesso avisa o cuidador; aos 12 min para de tocar e alerta cuidador
    e familiares. Depois disso a dose fica pendente e o botão ainda abre.
    - Se o paciente acessar depois de um aviso, quem foi avisado recebe
    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
2026-09-26 Adiciona MODO_TESTE com avisos aos 30 s e 60 s para testar em bancada
    Com MODO_TESTE = 1 o alarme avisa o cuidador aos 30 s, alerta todos aos
    60 s e alterna 5 s tocando / 5 s em silêncio. Voltar para 0 restaura os
    tempos reais (6 e 12 minutos, ciclo de 1 minuto).
    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
2026-09-26 Ajusta o texto das mensagens de aviso do WhatsApp
    - Cuidador (primeiro aviso): Paciente “Nome” não acessou o medicamento
    das “HH:MM” horas.
    - Cuidador e familiares (alerta final): Paciente “Nome” não foi até o
    dispenser no horário das “HH:MM”.
    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
2026-09-26 Adiciona o prefixo "Zelo+:" às mensagens de aviso
    Como o CallMeBot envia de um número próprio, o prefixo identifica que o
    aviso veio do dispenser.
    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
2026-09-26 Troca o envio de avisos do CallMeBot (WhatsApp) para um bot do Telegram
    O CallMeBot ficou sem vagas para novos números e o plano gratuito é só
    para uso pessoal. Os avisos passam a sair por um bot do Telegram criado
    pelo cuidador no @BotFather:
    - Página ganha o campo "Token do bot" (em branco mantém o salvo) e o
    botão "Buscar IDs do Telegram", que lista nome e ID de quem tocou em
    Iniciar no bot, para copiar para cada contato.
    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
2026-09-26 Adiciona histórico de doses com resumo de adesão e exportação CSV
    - Cada disparo de alarme gera um registro (data/hora, situação e atraso)
    guardado em Preferences num buffer circular das últimas 60 doses.
    - Situações: tomada no horário (antes do primeiro aviso), tomada com
    atraso, sem acesso (alerta final enviado) e tocando agora.
    - A página mostra o resumo dos últimos 7 dias com percentual de adesão,
    as 20 doses mais recentes, link para baixar a planilha CSV e botão
    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
2026-09-26 Suporte a 3 compartimentos de medicamentos (Zelo+ v2)
    Implementa a especificação aprovada em docs/compartimentos.md:
    - Até 3 medicamentos, cada um fixo no seu compartimento (servos nos
    GPIO 13, 14 e 27), com até 6 horários cada. A página indica onde
    colocar cada remédio e guarda a ligação medicamento-compartimento.
    - Abastecimento guiado: compartimentos com medicamento novo abrem um de
    cada vez; troca de medicamento pede para retirar os comprimidos
    antigos; opção de esvaziar compartimento.
    - Reposição pergunta qual medicamento será reposto e abre só o
    compartimento dele.
    - Remédios no mesmo horário tocam num único alarme; um toque abre todos
    os compartimentos d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
    [main.cpp]
2026-09-26 Adiciona guia didático passo a passo e diagrama de ligações
    - README-DIDATICO.md: explica o funcionamento do firmware em 18 passos,
    na ordem em que acontece, com o trecho de código de cada etapa
    (conferido contra src/main.cpp), linha do tempo de uma dose,
    referência rápida e exercícios.
    - docs/ligacoes.svg/.png: diagrama com todas as ligações no ESP32
    DevKit (3 servos, LCD I2C, buzzer, LED, botão e fonte externa 5 V).
    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
2026-09-27 Adiciona versão em PDF do guia didático
    docs/Zelo-Guia-Didatico.pdf: capa, sumário com links, diagrama de
    ligações e os 18 passos com os trechos de código destacados (A4,
    24 páginas), gerado a partir de README-DIDATICO.md.
    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
2026-09-27 Guia didático: print completo da página e ajustes de paginação do PDF
    - Nova seção A5 com a página do Zelo+ inteira (gerada pelo próprio
    handleRoot() com um cadastro de exemplo), a tela de reposição e uma
    tabela explicando cada área e o passo do guia correspondente.
    - Diagrama da rotina mais estreito; diagramas marcados como texto para
    não quebrarem linha no PDF.
    - PDF: trechos de código, diagramas, tabelas e imagens não são mais
    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
2026-09-27 Novo visual da página: cores por compartimento e blocos recolhidos
    Pensado para cuidadores e familiares com pouca familiaridade com
    tecnologia:
    - Letras e botões grandes; cada compartimento tem uma cor fixa
    (1 azul, 2 verde, 3 roxo) no cartão, na dica de abastecimento, na
    reposição e no histórico.
    - Remédios, paciente, cuidador e familiares aparecem recolhidos (só o
    nome/faixa); um toque abre os detalhes. Familiar novo fica atrás de
    "+ Cadastrar familiar".
    - Bloco do Telegram vai para o fim da página, depois de "Trocar rede
    Wi-Fi", e só aparece aberto (com aviso no topo) enquanto faltar o
    token ou o ID de alguém; os IDs saem dos cartões das pessoas.
    - Familiar remov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
    [main.cpp]
2026-09-27 Corrige compartimento sem mudança abrindo ao salvar outro remédio
    Um nome salvo por versões antigas com espaço no fim ("Losartana ") era
    comparado com o nome enviado pela página já sem o espaço, e o sistema
    entendia que o remédio do compartimento 1 tinha sido trocado, abrindo-o
    para abastecimento ao cadastrar um remédio no compartimento 2.
    - Nomes (paciente, remédios e contatos) são limpos também ao carregar
    da memória e na migração.
    - A comparação "remédio mudou?" ignora espaços nas pontas e maiúsculas.
    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
    [main.cpp]
2026-09-27 Documenta uso autônomo (fonte própria/bateria) e sugere relógio DS3231
    - Guia didático ganha a Parte D, condicional: só aplicar após os testes
    e a gravação da versão final (checklist D1). Descreve carregador USB,
    fonte única 5 V no VIN com capacitor, bateria/power bank "nobreak",
    consumo, comportamento em falta de energia/internet e o módulo de
    relógio DS3231 recomendado para a próxima versão (com esboço de uso).
    - Novo diagrama docs/ligacoes-autonomo.svg/.png; o diagrama de bancada
    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
2026-09-27 Uso autônomo: solução única com fonte 5 V/3 A + IP5306 + bateria 18650
    Substitui as opções anteriores da Parte D (carregador USB, fonte única,
    power bank) por uma única montagem recomendada:
    - Fonte de tomada 5 V/3 A (USB-C) → módulo IP5306 (carrega a bateria e
    entrega 5 V com ou sem energia da rua) → VIN do ESP32, servos e
    capacitor; uma bateria 18650 ligada em B+/B−.
    - Lista de compras completa, incluindo o cabo USB-C com fios para
    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
2026-10-11 Acionamento da tampa para o gabinete impresso: alavanca, braco do servo e pino com argola
    Pecas em cad/ (STL, OpenSCAD editavel e gerador), cinematica verificada:
    eixo da dobradica 13,8 mm atras da divisoria, servo com curso de 47 graus,
    alavanca a 1,5 mm da divisoria com a tampa aberta. Guia (B1, B3, B4, B5, G2)
    e desenhos atualizados com as novas medidas das tampas.
    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
    [alavanca-tampa.stl, braco-servo.stl, pino-argola.stl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]
2026-10-11 Modelo 3D completo do gabinete (prototipo com protoboard)
    cad/gabinete.py gera corpo, bandeja, fundo removivel, tampas, tampa tecnica e
    trava de moeda, com suportes dos servos, olhais das dobradicas, berços da
    protoboard, do UPS, do relogio e do capacitor, alojamento do buzzer com furos
    de som (lateral esquerda), recorte do USB-C (lateral direita), suportes da
    tela, do botao e do LED. Conferencia de colisoes parada e em movimento sem
    nenhuma interferencia. Guia: B6, B1, B3, B4, E10 e desenhos atualizados.
    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
    [bandeja.stl, componentes.stl, corpo.stl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]
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
